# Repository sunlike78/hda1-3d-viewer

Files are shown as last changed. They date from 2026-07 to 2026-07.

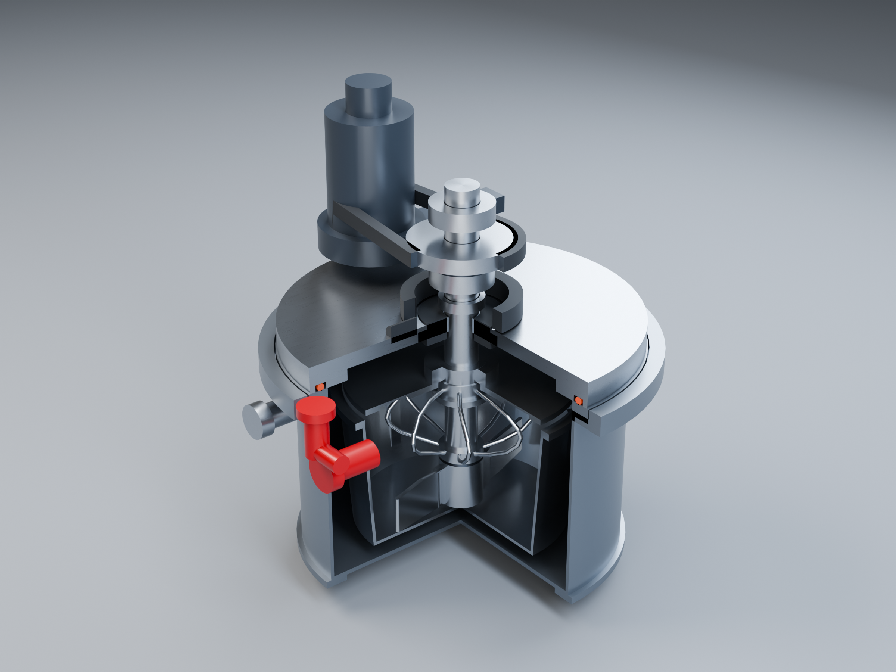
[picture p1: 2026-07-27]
assets/p1/hda1_p1_main_node_photoreal.png

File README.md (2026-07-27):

# HDA-1 interactive 3D viewer

Static GitHub Pages viewer for the HDA-1 domestic foamed-dough appliance main
node. It loads the reviewed STL exports directly, preserves the millimetre
coordinate system, and supports orbit, zoom, pan, cutaway, dimensions, and
per-part visibility.

The visible 11 mm pressure-shell wall and 12 mm bottom are P0 visualization
placeholders, not production dimensions. Pressure boundary, welds, lid, and
lock require a separate code calculation and physical validation.

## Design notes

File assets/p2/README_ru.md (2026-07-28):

# HDA-1 / P2 — предварительный пакет документации

## Главный файл

`hda1_p2_preliminary_documentation_package_ru.pdf` — единый проверенный PDF на 15 страниц:

1. титул, границы проработки и техническая архитектура;
2. ведомость узлов, расчётная сводка и программа верификации;
3. расчёты вала, привода, муфты, подшипников, подачи воздуха, давления, замка и декомпрессии;
4. трассируемость расчётов и ограничения;
5. сборочный лист GA-03 и мобильная обзорная страница с 3D-рендером;
6. GA-05 — подробный сборочный reference-лист, построенный по параметрам нативной модели FreeCAD;
7. приложение с фактическим CAD-рендером из FreeCAD.

## Нативная CAD-модель

- `../freecad/HDA1_P2_Master.FCStd` — исходная параметрическая сборка FreeCAD 1.1.3;
- `../freecad/HDA1_P2_Master.step` — обменная модель STEP;
- `../freecad/HDA1_P2_GA05_Detailed_Reference.pdf` — отдельный лист GA-05;
- `../freecad/HDA1_P2_CAD_Cutaway.png` — CAD-рендер контрольного разреза.

Конструктивное правило, проверяемое во всех материалах: форма имеет сплошное дно, нижней опоры вала в чаше нет; вал поддержан только верхней сухой головкой. Красный элемент на рендере — независимый механический предохранительный клапан.

## Статус

Это предварительная конструкторская проработка P2, а не рабочая документация для изготовления сосуда под давлением. Перед прототипом нужны нормируемый расчёт камеры, крышки и замка, FEM/ресурс, подбор серийных компонентов и физические испытания.

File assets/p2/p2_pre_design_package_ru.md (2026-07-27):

# HDA-1 — пакет P2 для прототипа главного узла

**Версия:** P2 / 28.07.2026  
**Назначение:** предконструкторская база для функционального прототипа бытовой машины на 350–500 г аэрированного теста.  
**Статус:** не является серийной КД, расчётом сосуда по нормам, сертификатом или разрешением на самостоятельное изготовление сосуда под давлением.

## 1. Что изменилось по сравнению с P1

- Убран художественный гибрид лопастей без доказанной функции.
- Появилась P2-форма с постоянным внутренним Ø150 мм, высотой 95 мм и объёмом 1,679 л.
- Новая мешалка имеет реальный параметрический контур: две открытые ленточные спирали и исследовательское щелевое кольцо.
- Подтверждены цифровые зазоры: 7,989 мм по радиусу и 8,0 мм до цельного дна.
- Вал приведён к Ø20 мм; введены расчётные пределы 12 Н·м длительно / 24 Н·м кратковременно.
- Рабочее давление не объявлено заранее: +20 / +40 / +60 кПа — только стендовые точки исследования.

## 2. Параметры P2

| Параметр | Принято |
|---|---:|
| Порция | 350–500 г |
| Форма | Ø150 × 95 мм, 1,679 л номинального геометрического объёма |
| Давление стендовых рецептов | +20 / +40 / +60 кПа |
| Внутренний диаметр камеры | 210 мм |
| Номинальная оболочка P1, сохранённая в P2 | 2,5 мм; нижнее замыкание 3 мм — только до нормального расчёта |
| Крышка / замок | пластина 10 мм; 8 проушин 7 × 18 мм — screening-конверт P1 |
| Мокрый вал | Ø20 мм, кандидат 1.4404/316L |
| Мешалка A | Ø134,02 мм; две открытые ленты |
| Радиальный зазор до формы | 7,989 мм |
| Нижний зазор до цельного дна | 8,0 мм; нижней опоры нет |
| Замес / диспергирование | 50–120 / 180–360 об/мин, исследовательские диапазоны |
| Лимит момента | 12 / 24 Н·м |

## 3. Концептуальный BOM

| Поз. | Узел | Кол. | Кандидат исполнения | Статус |
|---:|---|---:|---|---|
| 1 | Стационарная камера | 1 | 1.4404/316L, сварная, гладкая внутренняя поверхность | Нужен кодовый расчёт |
| 2 | Крышка с верхней головкой | 1 | Нерж. основание + сухой приводной модуль | Нужны FEM и шарнир/рама |
| 3 | Самоблокирующееся кольцо | 1 | 8-проушинная механика | Нужны контакт/усталость |
| 4 | Статическое уплотнение крышки | 1 | Пищевой силикон или FKM по среде | Нужны ресурс и поставщик |
| 5 | Съёмная форма | 1 | Гладкая нержавеющая сталь либо валидированный алюминиевый вариант | Нужна выпечка/мойка |
| 6 | Мешалка A | 1 | Электрополированная нержавеющая сталь, открытая геометрия | Базовый стендовый кандидат |
| 7 | Мокрый вал и муфта | 1 | Ø20 мм, 4 кулачка | Нужны износ/фиксация |
| 8 | Подшипниковый картридж | 1 | 2 подшипника Ø20 вне продуктовой зоны | Нужен конкретный тип |
| 9 | Торцевое уплотнение | 1 | Сменная двойная кассета с дренажной полостью | Нужна квалификация |
| 10 | Привод | 1 | BLDC 600 Вт класса + редуктор + ограничение момента | Нужен подбор |
| 11 | Управляемый выпуск | 1 | НЗ-клапан + ловушка аэрозоля + сменный ограничитель | Нужны расходные испытания |
| 12 | Предохранительный клапан | 1 | Независимый сертифицируемый покупной узел | Настройка только после расчёта |
| 13 | Датчики давления | 2 | Независимые каналы | Нужна диагностика и калибровка |
| 14 | Датчики RPM/тока/температуры/замка | комплект | Независимый контроль процесса | Нужна FMEA |

## 4. Требования к прототипу

1. Вал, инструмент и форма не получают нижней опоры.
2. Крышка не разблокируется по одному датчику или только программой.
3. Рабочий и предохранительный выпуск не объединяются после камеры.
4. Запуск под давлением запрещён при неопознанной форме, неустановленной мешалке, рассогласовании P1/P2 или ненулевых RPM.
5. Нагрузка выше 24 Н·м прекращает замес до прессуризации.
6. Форма, инструмент, экран и уплотнение снимаются без ключа и остаются визуально проверяемыми.

## 5. Ворота перехода P2 → физический прототип

- 54 тестовых цикла по матрице A/B × 20/40/60 кПа × 3 профиля сброса × 3 повтора;
- выбрана одна рецептура для первого окна, без маркетинговых медицинских обещаний;
- результат повторяется минимум в 9 из 10 циклов;
- измерены момент, температура, давление, объём/плотность, оседание и структура после выпечки;
- до давления выше стендового диапазона выполнены профессиональный расчёт, гидроиспытание и валидация клапана.

## 6. Связанные материалы P2

- `main_node_p2.scad` — главная параметрическая сборка;
- `p2_mixer_variants.scad` — варианты A и B;
- `p2_design_basis_ru.md` — входные требования и ограничения;
- `p2_mixer_decision_ru.md` — логика выбора рабочего органа;
- `p2_drive_shaft_screening_ru.md` — привод, вал, муфта, подшипники и воздух;
- `p2_pressure_vent_screening_ru.md` — замок и управляемая декомпрессия;
- `output/drawings/hda1_p2_ga02_ru.svg` — сборочный лист GA-02;
- `output/renders/hda1_p2_main_node_photoreal.png` — проверенный P2-рендер.

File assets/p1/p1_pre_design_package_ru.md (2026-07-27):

# HDA-1 P1 — предконструкторский пакет главного узла

Версия: P1 · дата: 27.07.2026 · статус: **предконструкторская разработка для
прототипа**, не производственная КД и не разрешение на изготовление сосуда.

P1 заменяет только чрезмерно толстую визуальную оболочку P0. Принцип процесса,
съёмная форма, верхнеопорный вал и гибридная мешалка остаются прежними.

## 1. Паспорт P1

| Позиция | Значение P1 | Статус |
|---|---:|---|
| Нормальное давление процесса | до +0,15 МПа | целевое для прототипа |
| Расчётное давление PS | +0,25 МПа | зафиксировано для screening |
| Гидроиспытание | +0,325 МПа | только после расчёта ответственного инженера |
| Расчётная температура TS | до 60 °C | предварительно |
| Камера, внутренний Ø | 210 мм | базовый размер |
| Оболочка камеры | 1.4404 / 316L, номинально 2,5 мм | P1, требует расчёта по нормам |
| Нижнее закрытие камеры | 1.4404 / 316L, номинально 3,0 мм | P1, требует расчёта по нормам |
| Верхний фланец | Ø238 × 10 мм | P1-концепт |
| Крышка | Ø236 × 18 мм; несущая плита 10 мм | P1-концепт |
| Поворотное кольцо | Ø260 × 14 мм; 8 зацепов | P1-концепт |
| Съёмная форма | Ø160 / Ø146 × 92 мм внутри | не является сосудом |
| Полный габарит узла с портами | примерно 282 × 261 × 306 мм | по STL P1 |

## 2. Базы, критические интерфейсы и предварительные допуски

| Обозначение | База / интерфейс | Требование P1 | Почему это критично |
|---|---|---|---|
| A | кольцевая плоскость посадки крышки | плоскостность ≤0,10 мм на дорожке уплотнения | герметичность |
| B | ось вращающегося уплотнения и вала | биение мокрой шейки ≤0,03 мм относительно оси подшипников | ресурс торцевого уплотнения |
| C | три наружных ключа формы | угловое позиционирование ±1°; радиальный люфт ≤0,30 мм | форма не проворачивается |
| D | нижний торец мешалки — внутреннее дно формы | зазор 7,0 ±1,0 мм | нет контакта с чашей, но остаётся перенос теста |
| E | мешалка — стенка формы | радиальный зазор не менее 12 мм | исключение касания при биении |
| F | дорожка статической прокладки | обжатие 15–25 % по паспорту выбранного материала | герметичность без разрушения прокладки |
| G | зацепы кольца | 8 × (7 мм × 18 мм); суммарный рабочий зазор 0,20–0,40 мм | закрытие под давлением |

Размеры B, F и G не должны попадать в производство без итоговой FEA, выбора
уплотнения, цепи допусков и расчёта зацепов. Для мокрой шейки вала в P1
задаётся шлифованная поверхность `Ra ≤ 0,4 мкм`; финальная посадка выбирается
по конкретной кассете уплотнения.

## 3. Состав изделия P1

| Поз. | Наименование | Кол. | Материал / тип | Статус |
|---:|---|---:|---|---|
| 01 | Обечайка камеры с верхним фланцем | 1 | 1.4404, 2,5 мм | собственная, расчёт + WPS/PQR обязательны |
| 02 | Нижнее закрытие камеры с боковым дренажом | 1 | 1.4404, 3,0 мм | собственная, расчёт + WPS/PQR обязательны |
| 03 | Силовая крышка | 1 | 1.4404, плита 10 мм | собственная, FEA обязательна |
| 04 | Поворотное кольцо и восемь зацепов | 1 | 1.4404 | собственная, стендовая проверка обязательна |
| 05 | Статическая прокладка | 1 | пищевой силикон/FKM | покупная, материал и обжатие по поставщику |
| 06 | Съёмная форма | 1 | 1.4301/1.4404, 2,2 мм | продуктовая, не силовая |
| 07 | Вал Ø22 | 1 | 1.4404, шлифованный | собственный/покупной |
| 08 | Два радиально-упорных подшипника | 2 | закрытые, сухая зона | покупные, подбор по нагрузке и ресурсу |
| 09 | Кассета торцевого уплотнения | 1 | пищевое исполнение | покупная/разработка, ресурсный тест |
| 10 | Мешалка P0-hybrid | 1 | 1.4404: лопасти 3 мм, прутки Ø3 мм | прототип, сварка в приспособлении |
| 11 | Датчики давления P1/P2 | 2 | независимые, диапазон с запасом над PS | покупные, проверка канала |
| 12 | Управляемый выпуск | 1 | отдельный клапан | покупной, flow sizing обязателен |
| 13 | Независимый предохранительный клапан | 1 | сертифицированный пружинный | покупной, уставка ≤ PS, расчёт пропускной способности |
| 14 | Датчики замка и формы | 3+ | концевые / бесконтактные | покупные, функциональная безопасность |

Ни резьбы, ни разъёмный крепёж не допускаются в зоне контакта с продуктом.
Сварные швы мешалки зачищаются и электрополируются; шероховатость продуктовых
поверхностей назначается отдельной технологической картой.

## 4. Силовая логика

`давление → крышка → 8 зацепов кольца → верхний фланец → обечайка → нижнее закрытие`.

Мотор, ремень, подшипники, подъёмная кинематика и внешний корпус не являются
частью силовой границы давления. Вал не имеет нижней опоры: его конец и
мешалка находятся на 7 мм над цельным дном съёмной формы. Боковой дренаж
камеры находится за пределами контура формы.

## 5. Обязательная программа квалификации P1

1. **Документальный gate:** утверждение PS/TS, среды, материалов, расчетного
   маршрута, WPS/PQR, NDT и независимого предохранительного клапана.
2. **FEA / расчёт:** оболочка, нижнее закрытие, крышка с отверстием вала,
   фланец, зацепы, контакт прокладки, штуцеры и усиления отверстий.
3. **Герметичность:** пневматическая проверка на безопасном низком давлении с
   защитным экраном и протоколом; гидроиспытание только по утверждённой
   процедуре и после пункта 1–2.
4. **Замок:** минимум 10 000 циклов закрытия/открытия как P1-screening;
   после — контроль износа, усилия поворота и геометрии зацепов.
5. **Сброс:** заблокированный управляемый выпуск, проверка независимого
   клапана, регистрация давления и времени снижения давления.
6. **Привод:** контроль момента, тока, вибрации и биения; отключение при
   заклинивании; проверка 7-мм зазора после ресурса.
7. **Пищевая часть:** разборка без инструмента, мойка, осмотр застойных зон,
   смыв/экстракция после продукта и проверка поверхности.

## 6. Выпуск P2 — что ещё нужно

P2 может быть объявлен только после закрытия FEA/расчётов, испытаний P1,
выбора серийных покупных компонентов, комплекта чертежей с допусками и
спецификациями, FMEA, риск-анализа, инструкций и маршрута соответствия.

Официальная нормативная граница: PED 2014/68/EU относится к оборудованию с
максимальным допустимым давлением выше 0,5 бар; перечень гармонизированных
стандартов поддерживается Европейской комиссией. [PED](https://eur-lex.europa.eu/legal-content/EN/TXT/?qid=1782329382909&uri=CELEX%3A02014L0068), [гармонизированные стандарты](https://single-market-economy.ec.europa.eu/single-market/goods/european-standards/harmonised-standards/pressure-equipment_en).

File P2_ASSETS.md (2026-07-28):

# HDA-1 — пакет P2

Публичные материалы P2:

- `assets/p2/hda1_p2_main_node_photoreal.png` — проверенный фотореалистичный разрез;
- `assets/p2/hda1_p2_ga02_ru.png` — сборочный лист GA-02 на русском;
- `assets/p2/hda1_p2_ga02_ru.svg` — исходный вектор GA-02;
- `assets/p2/hda1_p2_ga02_ru.dxf` — нативный CAD-лист A3 (DXF R2013, слои и размерные примитивы);
- `assets/p2/hda1_p2_mobile_preview_ru.pdf` — двухстраничный просмотр: фоторендер для телефона и лист GA-02 A3;
- `assets/p2/main_node_p2.scad` — параметрическая P2-сборка;
- `assets/p2/main_node_p1.scad` и `assets/p2/p2_mixer_variants.scad` — необходимые подключаемые исходники P2-сборки;
- `assets/p2/p2_pre_design_package_ru.md` — сводный P2-пакет и BOM;
- `assets/p2/p2_drive_shaft_screening_ru.md` — привод, вал, муфта и подшипники;
- `assets/p2/p2_pressure_vent_screening_ru.md` — давление, замок и выпуск;
- `assets/p2/p2_qa_report_ru.md` — цифровая проверка.

Статус: предконструкторская разработка P2. Это не КД для изготовления сосуда под давлением и не сертификация.

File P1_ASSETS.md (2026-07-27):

# HDA-1 — материалы P1

Публичные материалы предконструкторской версии P1:

- `assets/p1/hda1_p1_main_node_photoreal.png` — фотореалистичный рендер;
- `assets/p1/hda1_p1_technical_ru.png` — технический плакат на русском;
- `assets/p1/hda1_p1_ga01_ru.png` — сборочный лист GA-01;
- `assets/p1/main_node_p1.scad` — параметрическая исходная модель OpenSCAD;
- `assets/p1/p1_pre_design_package_ru.md` — BOM, допуски и требования;
- `assets/p1/p1_pressure_lock_screening_ru.md` — предварительная проверка корпуса и замка.

Статус: P1, предконструкторская разработка; не является сертифицированной заводской КД.

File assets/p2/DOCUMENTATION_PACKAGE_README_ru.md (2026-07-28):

# HDA-1 / P2 — предварительный пакет документации

## Главный файл

`hda1_p2_preliminary_documentation_package_ru.pdf` — единый проверенный PDF на 15 страниц:

1. титул, границы проработки и техническая архитектура;
2. ведомость узлов, расчётная сводка и программа верификации;
3. расчёты вала, привода, муфты, подшипников, подачи воздуха, давления, замка и декомпрессии;
4. трассируемость расчётов и ограничения;
5. сборочный лист GA-03 и мобильная обзорная страница с 3D-рендером;
6. GA-06 — подробные проекции и разрезы P2: экранная копия, полученная из нативного DXF экспортом LibreCAD;
7. приложение с фактическим CAD-рендером контрольного разреза из FreeCAD.

## Исходники CAD

- `HDA1_P2_Master.FCStd` — параметрическая сборка FreeCAD 1.1.3;
- `HDA1_P2_Master.step` — обменная BRep-модель STEP;
- `hda1_p2_ga06_detailed_projections_ru.dxf` — нативный исходник подробного листа GA-06;
- `hda1_p2_ga06_librecad_export.pdf` — прямой экспорт DXF из LibreCAD;
- `hda1_p2_ga06_screen_copy_ru.pdf` — проверенная компоновка GA-06, включённая в единый пакет;
- `hda1_p2_freecad_cutaway.png` — CAD-рендер контрольного разреза.

Конструктивное правило, проверяемое во всех материалах: форма имеет сплошное дно, нижней опоры вала в чаше нет; вал поддержан только верхней сухой головкой. Красный элемент на рендере — независимый механический предохранительный клапан.

## Проверки

Выполнены независимые численные проверки расчётов (вал/привод/подшипники, подача воздуха/нагрузка замка) и проверка нативной BRep-модели FreeCAD: 22 объекта, в том числе две твёрдотельные ленты, с ненулевыми объёмами и соблюдением отсутствия нижней опоры в чаше. Визуально проверены лист GA-06 и CAD-разрез, включённые в PDF.

## Статус

Это предварительная конструкторская проработка P2, а не рабочая документация для изготовления сосуда под давлением. Перед прототипом нужны нормируемый расчёт камеры, крышки и замка, FEM/ресурс, подбор серийных компонентов и физические испытания.

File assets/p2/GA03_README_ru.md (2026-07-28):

# GA-03 — актуальный CAD-лист

`hda1_p2_ga03_preliminary_ru.dxf` — лист A3 в DXF R2013.

Проверен открытием в LibreCAD 2.2.1.5: русские подписи читаются штатным
шрифтом `cyrillic_ii.lff`; виды, размерные цепи и текстовые зоны разнесены.
`hda1_p2_ga03_mobile_preview_ru.pdf` построен из той же DXF-геометрии для
быстрого просмотра на телефоне.

Статус: предконструкторская проработка P2, не документация для изготовления.

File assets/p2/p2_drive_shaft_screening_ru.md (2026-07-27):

# HDA-1 — P2: предварительный расчёт привода, вала и воздуха

**Статус:** прозрачный screening P2. Все цифры ниже — входные допущения для компоновки прототипа, а не сертификационные нагрузки.

## 1. Что именно проверено

Проверяется верхний консольный вал без нижней опоры в форме. В расчёте вал нагружен одновременно:

- пиковым крутящим моментом 24 Н·м;
- боковой силой 250 Н на рабочем органе;
- консольным вылетом 120 мм от нижней направляющей/подшипникового узла.

Такое сочетание намеренно жёстче, чем спокойное перемешивание. Оно имитирует густой комок теста и нештатное касание потока продукта, но **не** контакт лопасти с формой: контакт запрещён геометрией и должен быть исключён испытаниями.

## 2. Принятая P2-компоновка

| Элемент | Значение |
|---|---:|
| Мокрый вал | Ø20 мм, 1.4404/316L-кандидат |
| Свободный вылет | 120 мм |
| Нижняя опора в форме | Нет |
| Длительный лимит момента | 12 Н·м |
| Пиковый лимит момента | 24 Н·м, кратковременно |
| Замес | до 120 об/мин |
| Диспергирование | до 360 об/мин |
| Доступная мощность на валу | 450 Вт как допущение для привода 600 Вт класса |
| Свободный объём камеры | 3,6 л для пневматической оценки |

Рекомендуемая механическая схема: два подшипника в сухой головке, ниже них — сменная кассета торцевого уплотнения с дренажным промежутком; затем гладкий мокрый вал. Подшипники не находятся в продуктовой зоне.

## 3. Результаты механического screening

Использованы стандартные упрощённые зависимости для круглого консольного вала:

\[
\sigma_b = \frac{32M}{\pi d^3};\qquad
\tau = \frac{16T}{\pi d^3};\qquad
\sigma_v = \sqrt{\sigma_b^2+3\tau^2}
\]

| Результат | Значение |
|---|---:|
| Изгибающий момент | 30 Н·м |
| Напряжение изгиба | 38,20 МПа |
| Касательное напряжение от кручения | 15,28 МПа |
| Эквивалентное напряжение Мизеса | 46,47 МПа |
| Условный предел текучести 316L | 170 МПа — **не нормативное допускаемое** |
| Предварительный статический запас | 3,66 |
| Прогиб на конце консоли | 0,095 мм |
| Идеальная 1-я частота консоли без массы инструмента | 954 Гц |

Вывод: Ø20 мм — разумная стартовая величина. Это не «доказательство ресурса»: реальная модальная модель обязана включать массу ступицы, ленточного инструмента, муфты и гибкость опор. Даже при грубом понижающем коэффициенте рабочие 6 Гц (360 об/мин) находятся далеко от этой идеальной оценки.

## 4. Совместимость с приводом

| Режим | Момент | Обороты | Механическая мощность |
|---|---:|---:|---:|
| Тяжёлый кратковременный замес | 24 Н·м | 120 об/мин | 302 Вт |
| Диспергирование газа | 3 Н·м | 360 об/мин | 113 Вт |

При 450 Вт доступной механической мощности привод теоретически может выдать 35,8 Н·м на 120 об/мин. Поэтому электронное ограничение 24 Н·м и механическая предохранительная муфта — обязательны: мотор не должен быть источником разрушительной перегрузки.

## 4.1. Быстросъёмная муфта и подшипники

В CAD P2 показана четырёхкулачковая муфта. При радиусе передачи 15 мм пик 24 Н·м создаёт 400 Н на один из четырёх кулачков. Для минимального сечения кулачка 7 × 7 мм среднее касательное напряжение получается **8,16 МПа**. Это лишь первичная проверка среза: финальная муфта требует проверки контактного смятия, люфта, износа от циклов, мойки и фиксации против неполного зацепления.

Для подбора подшипника принят консервативный screening: динамическая грузоподъёмность 7 кН, эквивалентная нагрузка 500 Н и 360 об/мин. Формальный L10 получается около **127 000 часов**. Это не означает такой ресурс изделия: в реальной головке лимит зададут загрязнение, уплотнение, перекос, смазка, старт-стоп и конкретная выбранная серия подшипника. Практическое требование P2 — два подшипника Ø20 мм в сухой зоне, разнесённые по оси; окончательный тип выбирается после компоновки и поставщика.

## 5. Воздух: оценка времени набора давления

Для свободного объёма 3,6 л и насоса с номинальной подачей 6 нормальных л/мин:

| Стендовый уровень | Добавляемый воздух | Идеальное время набора |
|---|---:|---:|
| +20 кПа | 0,71 Нл | 7,1 с |
| +40 кПа | 1,42 Нл | 14,2 с |
| +60 кПа | 2,13 Нл | 21,3 с |

Это нижняя оценка: реальный насос теряет производительность с ростом давления, а клапаны и фильтры создают потери. Для программы следует закладывать минимум двукратный запас времени и оценивать утечки по отдельному тесту герметичности.

## 6. Что этот расчёт ещё не заменяет

- FEM вала, ступицы, ленты и опор с реальной массой;
- усталостную долговечность и ресурс подшипников;
- прочность быстроразъёмной муфты, сварных швов и крышки;
- расчёт торцевого уплотнения по фактической паре трения;
- измерение реального момента на рецептуре;
- расчёт предохранительного клапана и канала сброса.

Исходный код расчёта: [`calculations/p2_drive_shaft_screening.js`](calculations/p2_drive_shaft_screening.js).

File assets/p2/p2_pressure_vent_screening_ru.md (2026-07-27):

# HDA-1 — P2: давление, замок и контролируемый сброс

**Статус:** предварительная воспроизводимая проверка. Не является расчётом сосуда по EN 13445, расчётом предохранительного клапана или подтверждением безопасности.

## 1. Зачем считать два диапазона

В ТЗ нет принятой рабочей уставки давления. Поэтому P2 разделяет:

1. **исследовательский диапазон рецептуры**: +20 / +40 / +60 кПа;
2. **прежний структурный screening-конверт**: +250 кПа и предварительная гидропроба +325 кПа.

Это не разрешение работать на +250 кПа. Такой запас нужен только для того, чтобы не принять крышку/замок, рассчитанные лишь на первый эксперимент.

## 2. Усилие на крышке и восемь проушин

Для внутреннего диаметра камеры 210 мм площадь проёма равна 346,36 см². В расчёт добавлен 1,0 кН предварительного прижима уплотнения. Размер одной проушины принят 7 × 18 мм, количество — 8.

| Перепад давления | Давление на крышку | Полное усилие с уплотнением | На одну проушину | Среднее срезающее напряжение |
|---:|---:|---:|---:|---:|
| +20 кПа | 0,693 кН | 1,693 кН | 0,212 кН | 1,68 МПа |
| +40 кПа | 1,385 кН | 2,385 кН | 0,298 кН | 2,37 МПа |
| +60 кПа | 2,078 кН | 3,078 кН | 0,385 кН | 3,05 МПа |
| +250 кПа, screening-конверт | 8,659 кН | 9,659 кН | 1,207 кН | 9,58 МПа |
| +325 кПа, предварительная гидропроба | 11,257 кН | 12,257 кН | 1,532 кН | 12,16 МПа |

Числа показывают порядок усилий, но не заменяют проверку контакта кольца, изгиба крышки, сварки фланца, локального смятия проушин, эксцентриситета и усталости.

## 3. Контролируемая декомпрессия

Для свободного объёма 3,6 л переход с +60 до +2 кПа высвобождает примерно **2,06 нормального литра воздуха**. Для трёх режимов сброса получаются:

| Время сброса | Средний расход | Эквивалентный диаметр простой диафрагмы* |
|---:|---:|---:|
| 30 с | 4,12 Нл/мин | 0,72 мм |
| 60 с | 2,06 Нл/мин | 0,51 мм |
| 90 с | 1,37 Нл/мин | 0,41 мм |

\*Упрощённая оценка при среднем перепаде 30 кПа, коэффициенте расхода 0,62 и без аэрозоля. Это **не** чертёж дросселя.

Главный конструктивный вывод: отверстие 0,4–0,7 мм в пищевом воздушном тракте слишком чувствительно к загрязнению. Для P2 нужен не «микроотверстие в корпусе», а отдельный сменный дросселирующий картридж либо капиллярный ограничитель, расположенный после ловушки аэрозоля, вместе с нормально-закрытым управляемым выпуском. Независимый предохранительный клапан не должен зависеть от этого тракта.

## 4. Архитектура безопасного выпуска

```text
Камера ──> каплеуловитель/экран ──> управляемый НЗ-клапан ──> сменный ограничитель ──> глушитель ──> наружу
  └──────────────────────────────> независимый механический предохранительный клапан ────────> наружу
```

Пути физически раздельны после камеры. При отключении питания контроллер не открывает крышку; он переходит к безопасному сбросу через выбранную отказобезопасную механику, которую ещё надо определить электрически и испытать.

## 5. Переход к прототипу

На стенде сначала измеряются настоящие кривые давления без теста и с тестом. После этого выбираются:

- рабочее давление рецептуры;
- максимальная скорость набора давления;
- реальное время сброса;
- сечение и материал ограничителя;
- настройка сертифицированного предохранительного клапана.

Исходный код: [`calculations/p2_pressure_vent_screening.js`](calculations/p2_pressure_vent_screening.js).

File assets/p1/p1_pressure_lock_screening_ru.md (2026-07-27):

# HDA-1 P1 — предварительный расчёт силовой оболочки и замка

Дата: 27.07.2026. Расчёт предназначен для выбора разумной **геометрии P1**
перед FEA и расчётом по нормам. Он не является расчётом сосуда по EN 13445 и
не даёт права на изготовление или маркировку CE.

## Зафиксированные исходные условия P1

| Параметр | Принято |
|---|---:|
| Нормальная работа | до +0,15 МПа |
| Расчётное давление PS | +0,25 МПа |
| Предварительное гидроиспытание | +0,325 МПа |
| Расчётная температура | до 60 °C |
| Внутренний диаметр камеры | 210 мм |
| Расчётный объём оболочки | около 4,92 л |
| Материал-кандидат оболочки | 1.4404 / 316L |
| Принятая условная допускаемая величина | 115 МПа |
| Условный коэффициент сварного соединения | 0,85 |

При PS = 2,5 бар и объёме 4,92 л произведение PS·V составляет около
12,3 бар·л. Это не классификация по PED: она зависит от окончательной
конфигурации, группы среды, объёма, защитной арматуры и трактовки всего
изделия. Однако давление выше 0,5 бар уже попадает в область PED.

## Оболочка

Для первичного скрининга использована тонкостенная окружная мембранная модель:

`t = p·D / (2·f·η − p)`.

При +0,25 МПа расчётный мембранный минимум получается около **0,27 мм**, при
+0,325 МПа — около **0,35 мм**. Эти числа нельзя использовать как толщину
детали: в них нет минимальной технологической толщины, допуска проката,
формовки днища, сварных переходов, штуцеров, локальных концентраций,
усталости и коррозионного/полировочного припуска.

Для P1 принята **номинальная стенка 2,5 мм** и нижнее днище 3,0 мм с отдельным
верхним фланцем. Окружное напряжение такой оболочки составляет ориентировочно
6,3 МПа в нормальном режиме, 10,5 МПа при PS и 13,7 МПа при
гидроиспытании. Это только sanity check, а не доказательство прочности.

## Крышка

Крышка P1 — не массивный 28-мм цилиндр P0, а 10-мм верхняя несущая плита,
опирающаяся на кольцевой фланец. Упрощённая формула жёстко защемлённой круглой
пластины Ø210 мм даёт около 11,4 МПа при PS и 14,8 МПа при гидроиспытании.

В финальном расчёте обязательны: центральное отверстие под вращающееся
уплотнение, локальные контактные давления прокладки, жёсткость фланца,
деформация кольца и FEA.

## Поворотный замок

Принято 8 зацепов, каждый с толщиной 7 мм и длиной зацепления 18 мм.

| Проверка при гидроиспытании | Значение |
|---|---:|
| Сила от давления на Ø210 мм | 11,26 кН |
| Предварительное обжатие прокладки | 1,00 кН |
| Полная расчётная сила замка | 12,26 кН |
| На один из 8 зацепов | 1,53 кН |
| Площадь среза одного зацепа | 126 мм² |
| Среднее касательное напряжение | 12,2 МПа |
| Условный запас к 65 МПа | 5,3 |

Это только средний срез. До выпуска P1 в металл нужны контактный расчёт,
изгиб каждого зацепа, допуски поворотного кольца, усталость, защита от
самооткрывания, испытания предельной нагрузки и независимая блокировка при
ненулевом давлении.

## Обязательные ворота перед прототипом

1. Утвердить PS, TS, среду, объём и маршрут соответствия с ответственным
   инженером по оборудованию под давлением.
2. Выполнить EN 13445 / применимый расчёт камеры, днища, крышки, фланца,
   штуцеров, сварки и замка.
3. Выбрать сертифицированный предохранительный клапан с уставкой не выше PS,
   независимый от управляемого выпуска.
4. Провести гидроиспытание, проверку герметичности, ресурсные циклы замка,
   аварийный сброс и FMEA.

Нормативная граница: PED 2014/68/EU применяется к оборудованию с PS выше
0,5 бар. См. официальную [страницу Европейской комиссии](https://single-market-economy.ec.europa.eu/single-market/goods/european-standards/harmonised-standards/pressure-equipment_en) и [текст директивы](https://eur-lex.europa.eu/legal-content/EN/TXT/?qid=1782329382909&uri=CELEX%3A02014L0068).

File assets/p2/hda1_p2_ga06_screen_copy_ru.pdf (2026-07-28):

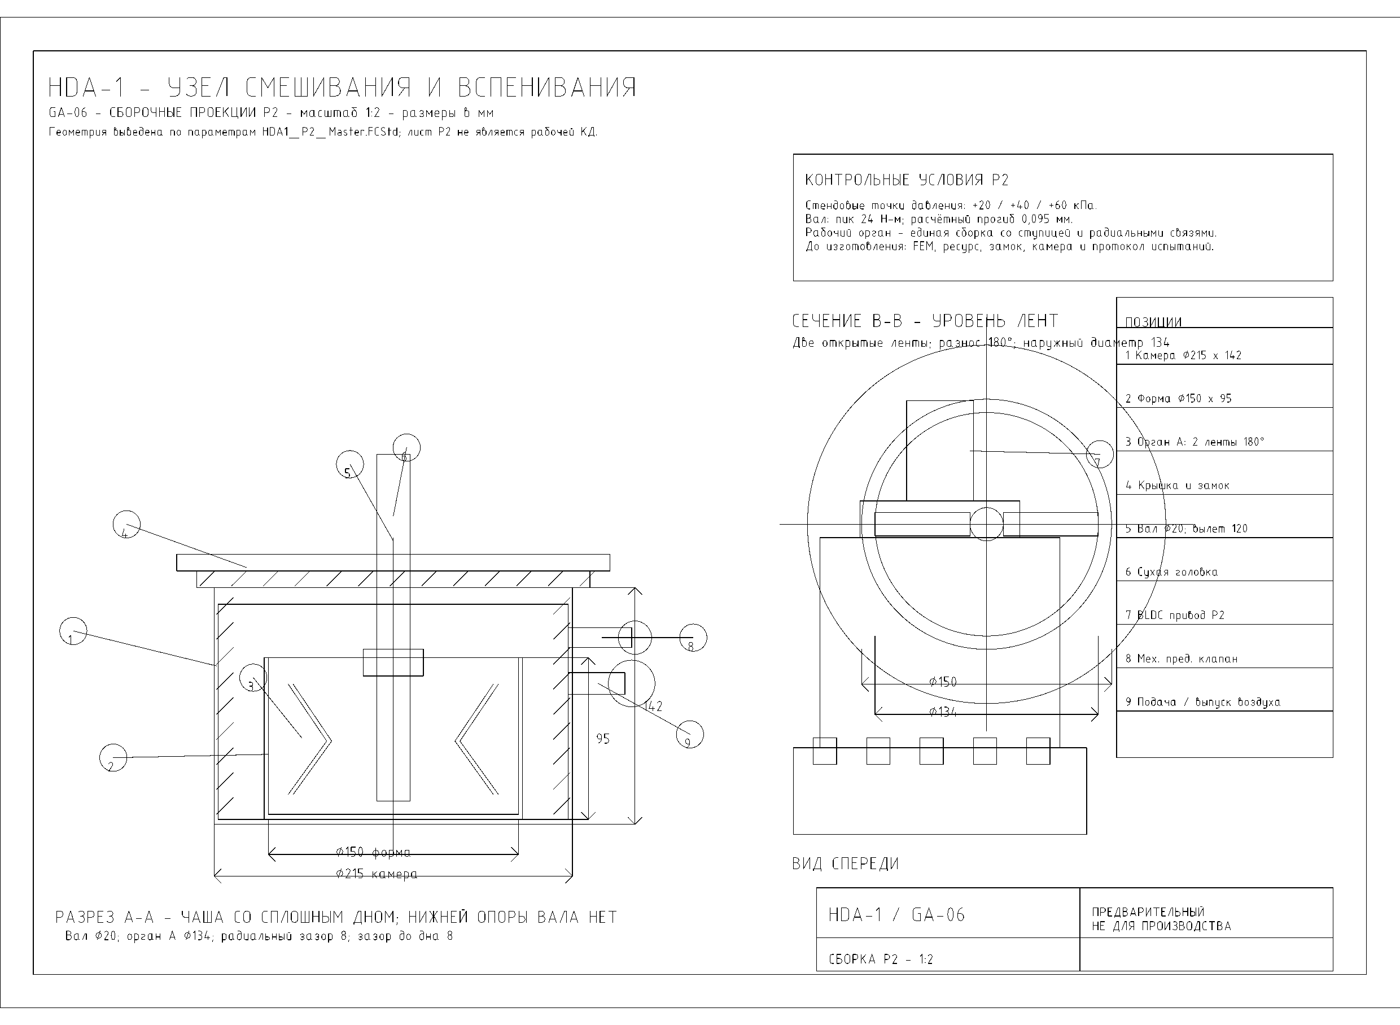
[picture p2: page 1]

GA-06 · экранная копия из нативного DXF, экспортированного LibreCAD | P2 · не для производства

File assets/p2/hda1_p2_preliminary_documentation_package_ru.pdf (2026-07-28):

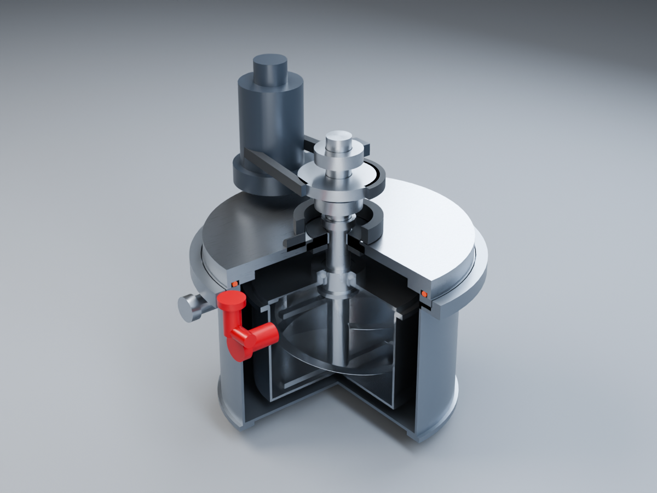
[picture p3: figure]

HDA-1 · P2 · ПРЕДВАРИТЕЛЬНЫЙ КОМПЛЕКТ · НЕ ДЛЯ ИЗГОТОВЛЕНИЯ | Стр. 1

# HDA-1

## Узел смешивания и вспенивания для бытовой машины

### СТАТУС: ПРЕДВАРИТЕЛЬНАЯ КОНСТРУКТОРСКАЯ ПРОРАБОТКА P2

Назначение: проверить компоновку верхнего привода, двухленточного инструмента и цельной съёмной

## формы без нижней опоры вала. Комплект объединяет исходные данные, скрининговые расчёты и

CAD-лист GA-03.

Это не серийная КД, не расчёт сосуда по нормам и не разрешение на самостоятельное изготовление оборудования под давлением.

HDA-1 · P2 · ПРЕДВАРИТЕЛЬНЫЙ КОМПЛЕКТ · НЕ ДЛЯ ИЗГОТОВЛЕНИЯ | Стр. 2

# 0. Статус и состав комплекта

Цель P2 — снять ключевые риски до изготовления прототипа: геометрию рабочего органа, отсутствие нижней опоры, ориентировочную прочность вала, чистоту силового пути и безопасность логики давления. Все численные режимы ниже — исходные для стенда, а не паспорт изделия.

Код | Документ / материал | Назначение
P2-DOC-01 | Настоящий комплект | Единая навигация, сводка решений и открытых пунктов.
GA-03 | Сборочный CAD-лист A3, 1:2 | Разрез A–A, вид сверху, базовые габариты и зазоры.
P2-CALC-01 | Скрининг вала, муфты, подшипников и воздуха | Проверка исходных допущений до FEM и стенда.
P2-SAFE-01 | Скрининг давления, замка и сброса | Разделение стендовых режимов и структурного конверта.
P2-QA-01 | Цифровая QA-проверка | Зазоры, отсутствие нижней опоры, визуальная связность модели.

## Граница ответственности

Перед изготовлением обязательны: финальная 3D-параметрическая модель, FEM и усталость, расчёт

### камеры/крышки/замка по применимой норме, подбор серийных подшипников и уплотнений, анализ

электробезопасности, протоколы мойки и физические испытания продукта.

HDA-1 · P2 · ПРЕДВАРИТЕЛЬНЫЙ КОМПЛЕКТ · НЕ ДЛЯ ИЗГОТОВЛЕНИЯ | Стр. 3

# 1. Техническая архитектура

Подсистема | Принятое решение P2 | Почему
Форма | Съёмная гладкая чаша Ø150; дно цельное. | Нет отверстия и нижнего подшипника в продуктовой зоне; проще очистка.
Мешалка | Две разнесённые на 180° открытые ленточные спирали, съёмная ступица. | Вертикально переносит вязкое тесто и динамически симметрична на 180–360 об/мин.
Вал и опоры | Мокрый вал Ø20; две опоры только в сухой головке сверху. | Сохраняет цельное дно и изолирует подшипники от продукта.
Уплотнение | Сменная двойная торцевая кассета с дренажной полостью. | Разделяет сухую головку и продуктовую зону; нужна квалификация.
Привод | BLDC класса 600 Вт + редуктор + ограничение момента. | Исходный диапазон 50–120 об/мин для замеса и 180–360 об/мин для диспергирования.
Давление | Стендовые точки +20 / +40 / +60 кПа; два датчика, замок, отдельный предохранительный путь. | Режим выбирается данными рецептуры; камера не получает рабочий паспорт из концепта.

Неподвижная нижняя опора, контакт мешалки с формой и открытие крышки при ненулевом давлении — запрещённые состояния конструкции P2.

HDA-1 · P2 · ПРЕДВАРИТЕЛЬНЫЙ КОМПЛЕКТ · НЕ ДЛЯ ИЗГОТОВЛЕНИЯ | Стр. 4

# 2. Ведомость основных узлов (P2)

Поз . | Наименование | Кол. | Материал / исполнение | Статус
1 | Корпус и крышка головки | 1 | Контактные поверхности: AISI 304 или эквивалент; окончательное исполнение TBD. | Компоновка подтверждена
2 | Съёмная форма Ø150 | 1 | Нержавеющая сталь либо валидированный алюминиевый вариант. | Нужны мойка и выпечка
3 | Двухленточный рабочий орган | 1 | Нержавеющая сталь; две симметричные ленты 180°. | Нужна балансировка
4 | Мокрый вал и 4-кулачковая муфта | 1 | Ø20 мм, кандидат 1.4404 / 316L. | Нужны износ и фиксация
5 | Подшипниковый картридж | 1 | Два подшипника Ø20 в сухой зоне. | Нужна конкретная серия
6 | Торцевое уплотнение | 1 | Сменная двойная кассета с дренажной полостью. | Нужна квалификация
7 | Привод | 1 | BLDC 600 Вт класса + редуктор + ограничение момента. | Нужен подбор
8 | Управляемый сброс | 1 | НЗ-клапан, ловушка аэрозоля, сменный ограничитель. | Нужны расходные испытания
9 | Датчики давления | 2 | Независимые каналы; диагностика рассогласования. | Нужны калибровка и логика

Контактные металлы и эластомеры должны быть уточнены по реальным поставщикам, моющим средам и температуре процесса. Данная ведомость — не закупочная спецификация.

HDA-1 · P2 · ПРЕДВАРИТЕЛЬНЫЙ КОМПЛЕКТ · НЕ ДЛЯ ИЗГОТОВЛЕНИЯ | Стр. 5

# 3. Расчётная сводка: что уже проверено

Проверка | Допущение | Результат | Инженерный вывод
Вал Ø20 | 24 Н·м пик; 250 Н боковая сила; консоль 120 мм. | σvM = 46,47 МПа; предварительный статический запас 3,66. | Подходит как стартовая величина; необходимы FEM, моды и усталость.
Муфта | 4 кулачка, радиус передачи 15 мм, сечение 7×7 мм. | Около 400 Н на кулачок; среднее касательное напряжение 8,16 МПа. | Нужны смятие, износ, люфт и защита от неполного зацепления.
Подшипники | C=7 кН; P=500 Н; 360 об/мин. | Формальный L10 ≈ 127 000 ч. | Не паспорт ресурса: лимит зададут перекос, уплотнение, мойка и серия.
Зазоры | CAD-измерение рабочего органа относительно формы. | Радиальный 7,989 мм; до цельного дна 8,0 мм. | Нижней опоры нет; касание формы должно быть исключено стендом.
Давление | Точки исследования +20/+40/+60 кПа. | Это матрица рецептуры; не принятое рабочее давление. | До повышения режима — нормированный расчёт, гидропроба и клапан.

Важно: скрининговый расчёт проверяет порядок величин и помогает не допустить явной компоновочной ошибки. Он не заменяет профессиональный расчёт сосуда под давлением, FEA и ресурсные испытания.

HDA-1 · P2 · ПРЕДВАРИТЕЛЬНЫЙ КОМПЛЕКТ · НЕ ДЛЯ ИЗГОТОВЛЕНИЯ | Стр. 6

# 4. Программа верификации и условия перехода к прототипу

Этап | Что измеряется | Критерий P2 | Далее
Геометрия | Зазоры, биение, балансировка, отсутствие нижней опоры. | ≥7 мм до формы и дна; нет контакта во всём диапазоне оборотов. | Уточнить допуски CAD и технологию изготовления.
Сухой прогон | RPM, ток, вибрация, температура головки, работа муфты. | Без резонансного режима и самопроизвольного расцепления. | Выбрать двигатель, редуктор, подшипники.
Продукт | Момент, температура, плотность/объём, оседание через 1/3/5/10 мин, выпечка. | Момент ниже лимита; достигнут целевой продуктовый критерий. | Выбрать геометрию A/B и режим.
Герметичность | Кривая давления, утечки, контролируемый сброс, P1/P2. | Крышка не открывается до подтверждённого нулевого давления. | Валидировать клапан и межблокировки.
Конструкция | Расчёт камеры/крышки/замка, FEM, сварка, очистка. | Выполнены квалифицированными специалистами по применимым нормам. | Только затем — рабочая КД и испытательный образец.

Переходный критерий: одновременно закрыты геометрический, механический, технологический и безопасностный контуры. Ни один из них не может быть заменён красивым 3D-рендером или только расчётом вала.

## Далее в составе пакета приведён актуальный нативный CAD-лист GA-03 и его

мобильная обзорная страница.

HDA-1 · P2 · ПРЕДВАРИТЕЛЬНЫЙ КОМПЛЕКТ · НЕ ДЛЯ ИЗГОТОВЛЕНИЯ | Стр. 7

# 5. Полный расчётный лист: вал и привод

Модель: верхний круглый консольный вал без нижней опоры в форме. Расчётная комбинация — пиковый крутящий момент T = 24 Н·м, боковая сила F = 250 Н, свободный вылет L = 120 мм, диаметр d = 20 мм. Она моделирует жёсткий ком теста, а не касание инструмента о форму: такое касание конструктивно запрещено.

Шаг | Формула / подстановка | Результат
Изгибающий момент | M = F × L = 250 × 0,120 | 30 Н·м
Изгиб | sigma_b = 32M / (pi × d³) | 38,20 МПа
Кручение | tau = 16T / (pi × d³) | 15,28 МПа
Совместное напряжение | sigma_v = sqrt(sigma_b² + 3 × tau²) | 46,47 МПа
Условный статический запас | n = 170 / 46,47; 170 МПа — ориентир текучести 316L, не нормативный допуск | 3,66
Прогиб консоли | delta = F × L³ / (3 × E × I), E = 193 ГПа | 0,095 мм
Идеальная частота | Консоль без массы инструмента | 954 Гц
Режим | Формула мощности | Результат | Вывод
Тяжёлый кратковременный замес | P = 2 × pi × n × T / 60; n=120; T=24 | 302 Вт | Ниже принятой доступной мощности 450 Вт.
Диспергирование газа | P = 2 × pi × n × T / 60; n=360; T=3 | 113 Вт | Режим требует проверки баланса и нагрева.
Потенциал привода | T = P × 60 / (2 × pi × n); P=450; n=120 | 35,8 Н·м | Нужны электронный лимит 24 Н·м и механическая защита.

Результат применим только как screening: реальная модальная модель должна включить массу ступицы и лент, реальные опоры, муфту, эксцентриситет и циклическую нагрузку. На 360 об/мин рабочая частота 6 Гц; сравнение с 954 Гц не является доказательством отсутствия резонанса в собранном узле.

HDA-1 · P2 · ПРЕДВАРИТЕЛЬНЫЙ КОМПЛЕКТ · НЕ ДЛЯ ИЗГОТОВЛЕНИЯ | Стр. 8

# 6. Полный расчётный лист: муфта, подшипники и набор давления

Проверка | Формула / подстановка | Результат | Ограничение
Четырёхкулачковая муфта | F_кулачка = T / (4 × r) = 24 / (4 × 0,015) | 400 Н | Распределение нагрузки в реальной муфте может быть неравномерным.
Срез кулачка 7×7 мм | tau = F / A = 400 / (7×7) | 8,16 МПа | Не проверены смятие, люфт, циклический износ и неполное зацепление.
Подшипники, L10 | L10h = (C/P)^3 × 10^6 / (60 × n); C=7000 Н; P=500 Н; n=360 | ≈127 000 ч | Формальный ресурс; не ресурс головки в мойке и с перекосом.

Подача воздуха: свободный объём V = 3,6 л; V_N = V × delta_p / p_atm; p_atm = 101,3 кПа; t = V_N / Q.

Стендовая точка | Добавляемый нормальный объём | Формула | Идеальное время при 6 Нл/мин
+20 кПа | 0,71 Нл | V_N = 3,6 × 20 / 101,3 | 7,1 с
+40 кПа | 1,42 Нл | V_N = 3,6 × 40 / 101,3 | 14,2 с
+60 кПа | 2,13 Нл | V_N = 3,6 × 60 / 101,3 | 21,3 с

Время — нижняя оценка. Реальный насос теряет подачу с ростом давления, а фильтры и клапаны дают потери; для эксперимента закладывается минимум двукратный запас времени и отдельный тест утечек.

HDA-1 · P2 · ПРЕДВАРИТЕЛЬНЫЙ КОМПЛЕКТ · НЕ ДЛЯ ИЗГОТОВЛЕНИЯ | Стр. 9

# 7. Полный расчётный лист: усилие на крышке и замок

Базовая геометрия: внутренний диаметр камеры D = 210 мм. Площадь проёма A = pi × D² / 4 = 0,034636 м² = 346,36 см². К усилию давления добавлен предварительный прижим уплотнения 1,0 кН. Принято восемь проушин 7×18 мм.

Перепад | Сила давления Fp = p × A | Итого F = Fp + 1,0 кН | На проушину F/8 | Среднее tau = F/(8×7×18)
+20 кПа | 0,693 кН | 1,693 кН | 0,212 кН | 1,68 МПа
+40 кПа | 1,385 кН | 2,385 кН | 0,298 кН | 2,37 МПа
+60 кПа | 2,078 кН | 3,078 кН | 0,385 кН | 3,05 МПа
+250 кПа, screening-конверт | 8,659 кН | 9,659 кН | 1,207 кН | 9,58 МПа
+325 кПа, предварительная гидропроба | 11,257 кН | 12,257 кН | 1,532 кН | 12,16 МПа

+250 кПа и +325 кПа — только структурный screening-конверт, а не разрешённое рабочее давление. Таблица даёт порядок усилий. Она не проверяет изгиб крышки, контакт кольца, сварки, локальное смятие проушин, эксцентриситет, усталость и сертифицированный предохранительный клапан.

Правило безопасности P2: крышка остаётся заблокированной при ненулевом давлении;

## два датчика P1/P2, независимый механический предохранительный путь и

управляемый выпуск имеют раздельные функции.

HDA-1 · P2 · ПРЕДВАРИТЕЛЬНЫЙ КОМПЛЕКТ · НЕ ДЛЯ ИЗГОТОВЛЕНИЯ | Стр. 10

# 8. Полный расчётный лист: контролируемая декомпрессия

Для свободного объёма 3,6 л переход от +60 кПа до +2 кПа высвобождает V_N = 3,6 × (60−2) / 101,3 = 2,06 Нл воздуха. Средний расход Q = V_N / t. Эквивалентное отверстие ниже вычислено упрощённо: Q = Cd × A × sqrt(2 × delta_p / rho), где Cd=0,62, средний перепад 30 кПа и аэрозоль не учитывается.

Время сброса | Средний расход | Эквивалентный диаметр простой диафрагмы | Конструкторское решение
30 с | 4,12 Нл/мин | 0,72 мм | Не делать микроотверстие в корпусе.
60 с | 2,06 Нл/мин | 0,51 мм | Сменный дроссель или капилляр после ловушки аэрозоля.
90 с | 1,37 Нл/мин | 0,41 мм | Отдельно подтвердить загрязняемость и повторяемость.

Расчёт объясняет, почему контролируемый выпуск не должен зависеть от случайной маленькой дырки: сечение 0,4–0,7 мм в пищевом воздушном тракте чувствительно к загрязнению. Предлагается отдельный сменный ограничитель после ловушки аэрозоля и нормально-закрытого управляемого клапана; независимый предохранительный клапан идёт отдельной ветвью.

Что не рассчитано этим пакетом: реальная характеристика насоса и клапанов, двухфазный поток с аэрозолем, конкретная настройка сертифицированного клапана, герметичность уплотнения и тепловой режим. Это измеряется на стенде и закрывается поставщиками компонентов.

HDA-1 · P2 · ПРЕДВАРИТЕЛЬНЫЙ КОМПЛЕКТ · НЕ ДЛЯ ИЗГОТОВЛЕНИЯ | Стр. 11

# 9. Трассируемость расчётов и честный статус

Раздел | Исходный материал / код | Что подтверждает
Геометрия и зазоры | P2 QA; параметрическая 3D-модель | 7,989 мм по радиусу; 8,0 мм до цельного дна; нижней опоры нет.
Мешалка | P2 решение по вариантам A/B | Базовый кандидат — две открытые ленты на 180°; вариант B экспериментальный.
Вал, привод, муфта, подшипники, воздух | calculations/p2_drive_shaft_screening.js | Воспроизводимые screening-значения, развёрнутые на стр. 7–8 PDF.
Давление, замок, выпуск | calculations/p2_pressure_vent_screening.js | Воспроизводимые screening-значения, развёрнутые на стр. 9–10 PDF.
CAD | GA-03, DXF R2013 | Разрез, вид сверху, базовые размеры и зазоры; не рабочая КД.

Итог: теперь PDF содержит все выполненные в P2 численные screening-расчёты, их формулы, подстановки, допущения и границы применимости. Это не означает, что узел «научно доказан» для производства. Для такого статуса остаются обязательными FEM, нормированный расчёт камеры и замка, ресурс, подбор покупных компонентов и физическая программа испытаний 2 геометрии × 3 давления × 3 профиля сброса × минимум 3 повтора = 54 цикла.

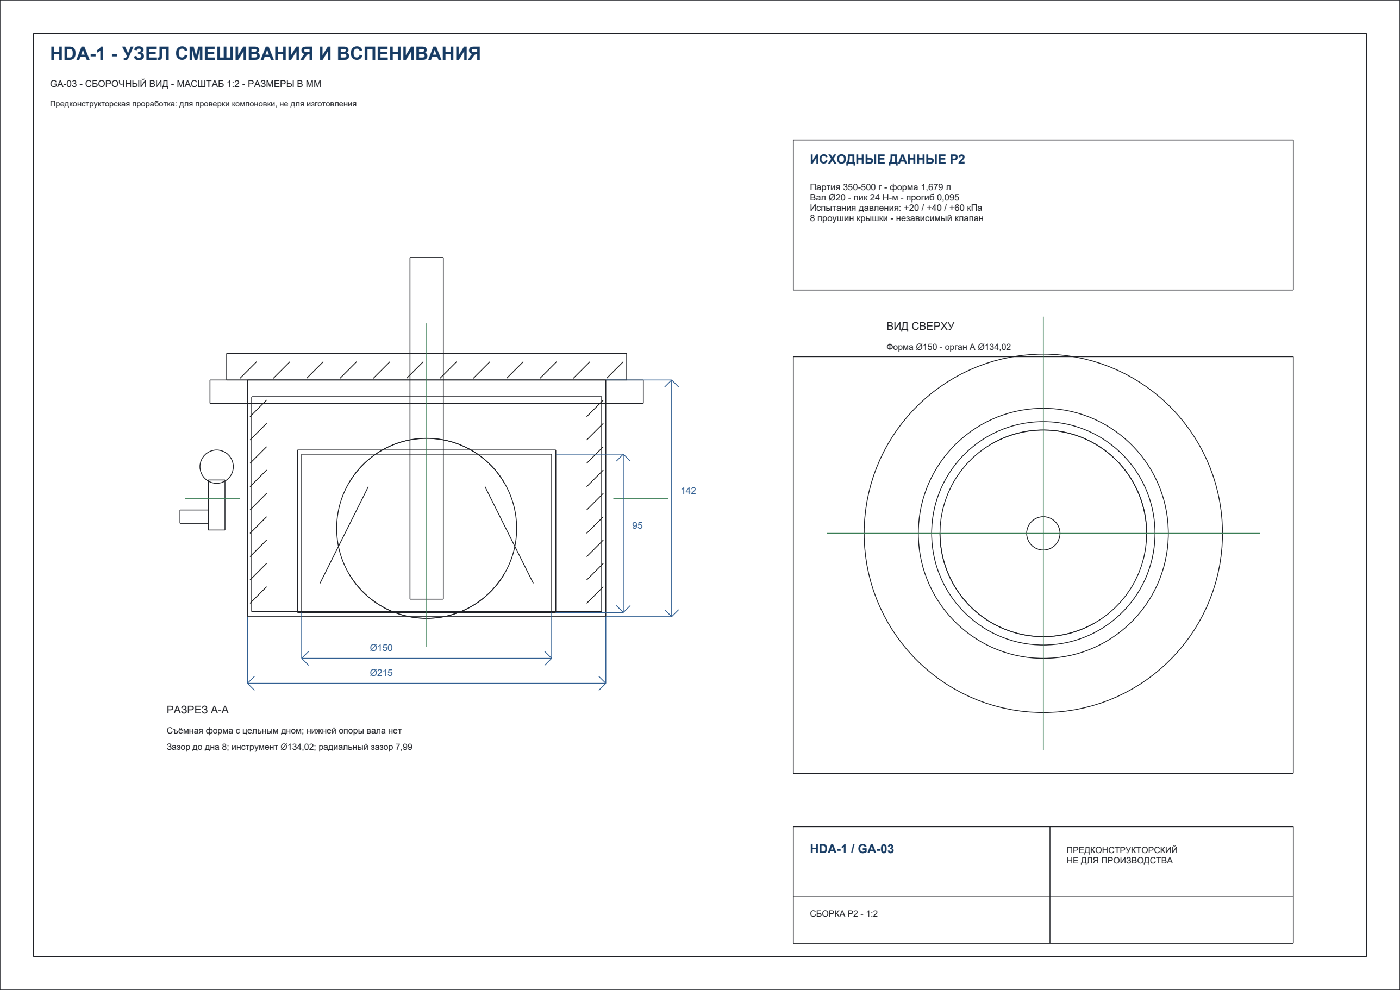
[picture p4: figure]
HDA-1 - УЗЕЛ СМЕШИВАНИЯ И ВСПЕНИВАНИЯ; РАЗРЕЗ А-А; ВИД СВЕРХУ; Форма Ø150 - орган A Ø134,02; ИСХОДНЫЕ ДАННЫЕ P2; Партия 350-500 г - форма 1,679 л Вал Ø20 - пик 24 Н-м - прогиб 0,095 Испытания давления: +20 / +40 / +60 кПа 8 проушин крышки - независимый клапан; СБОРКА P2 - 1:2

GA-03 - СБОРОЧНЫЙ ВИД - МАСШТАБ 1:2 - РАЗМЕРЫ В ММ

Предконструкторская проработка: для проверки компоновки, не для изготовления

Съёмная форма с цельным дном; нижней опоры вала нет

Зазор до дна 8; инструмент Ø134,02; радиальный зазор 7,99

HDA-1 / GA-03 | ПРЕДКОНСТРУКТОРСКИЙ НЕ ДЛЯ ПРОИЗВОДСТВА

# HDA-1 · главный узел P2

Предконструкторский просмотр. Не документ для производства.

## Что показано

- Бытовая партия: 350–500 г; съёмная форма Ø150 × 95 мм, 1,679 л.
- Рабочий орган A: две открытые ленточные спирали Ø134,02 мм.
- Вал Ø20 мм, передача через верхнюю муфту; нижней опоры в чаше нет.
- Зазор до цельного дна формы — 8 мм; радиальный зазор — 7,99 мм.
- Расчётный пик — 24 Н·м; испытательные давления: +20/+40/+60 кПа.

Технический лист — следующая страница (A3, альбомная).

Редактируемый первоисточник: hda1_p2_ga03_preliminary_ru_v4.dxf (DXF R2013).


GA-06 · экранная копия из нативного DXF, экспортированного LibreCAD | P2 · не для производства

# HDA-1 / P2 — CAD-РЕНДЕР ИЗ НАТИВНОЙ МОДЕЛИ FreeCAD

Проверочный разрез сборки: отдельные тела, чаша с цельным дном, верхний вал и внешние пневмоузлы.

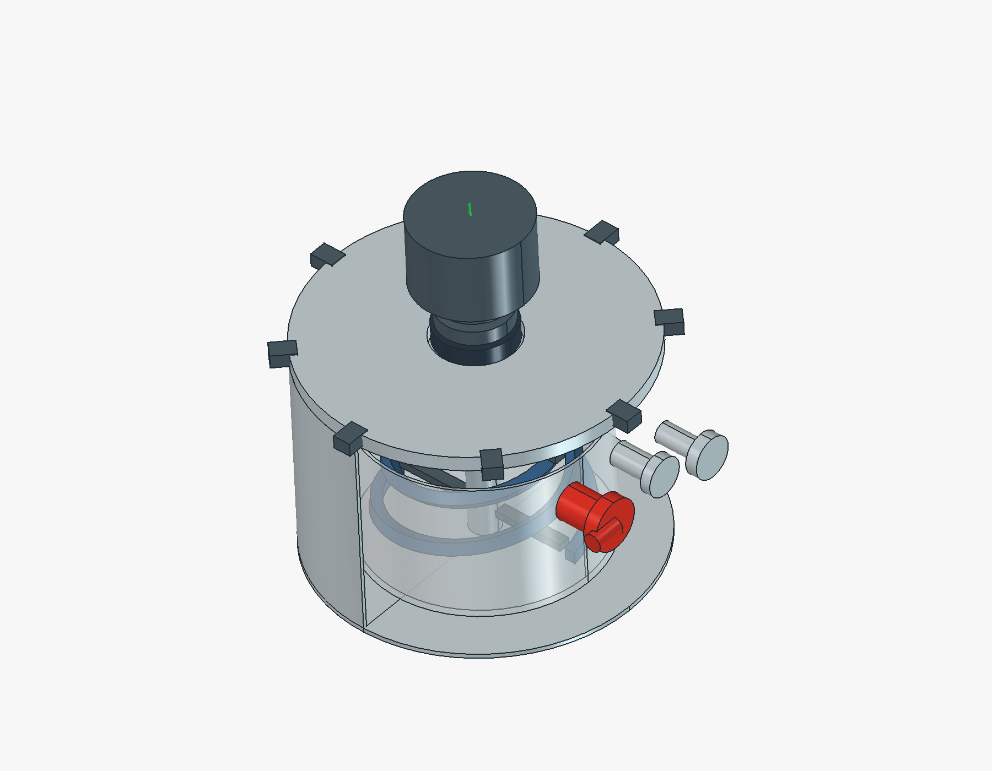
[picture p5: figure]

Что подтверждает этот кадр

- сборка открыта и сохранена в FreeCAD 1.1.3 как HDA1_P2_Master.FCStd;
- корпус показан половиной для визуальной проверки внутренней компоновки;
- нижний подшипник в форме отсутствует; красный элемент — независимый механический клапан;
- STEP-обменник и исходная FreeCAD-модель приложены отдельно.

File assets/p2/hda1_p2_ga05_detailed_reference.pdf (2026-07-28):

# HDA-1 — УЗЕЛ СМЕШИВАНИЯ И ВСПЕНИВАНИЯ

## GA-05 · ДЕТАЛЬНЫЙ СБОРОЧНЫЙ ЛИСТ ПО ПАРАМЕТРИЧЕСКОЙ МОДЕЛИ FreeCAD · P2

Размеры — опорные для прототипа; лист не является рабочей КД и не разрешает изготовление сосуда под давлением.

### Ø215 камера

### Ø150 форма

### Ø134 орган A

142

95

### зазор 8

### РАЗРЕЗ A–A · ЧАША С ЦЕЛЬНЫМ ДНОМ · НИЖНЕЙ ОПОРЫ ВАЛА НЕТ

1

2 3

4

5

### ВИД СВЕРХУ · ДЛЯ ПРОВЕРКИ ЗАЗОРОВ

Ø150

Ø134

Радиальный зазор: 7,989 мм

### ПОЗИЦИИ И КРИТИЧЕСКИЕ ПАРАМЕТРЫ

1 | Камера | Ø215 внешн. / Ø210 внутр. / H142; стенка 2,5 screening
2 | Съёмная форма | Ø150 × H95; дно цельное, нижней опоры нет
3 | Рабочий орган A | две открытые ленты 180°; Ø134; H76
4 | Крышка и замок | плита 10; 8 позиций замыкания
5 | Вал | Ø20; кандидат 1.4404/316L; вылет 120
6 | Сухая головка | 2 подшипника Ø20 + кассета уплотнения
7 | Привод | BLDC 600 Вт класса; лимит 12/24 Н·м
8 | Красный узел | независимый механический предохранительный клапан
9 | Пневмолинии | подача и управляемый выпуск — раздельные пути

### ПРОВЕРОЧНЫЕ УСЛОВИЯ P2

- давление рецептуры: +20 / +40 / +60 кПа — только стендовые точки;
- крышка открывается только после подтверждённого нулевого давления;
- зазоры измерены цифрово; окончательные допуски — после FEM и прототипа.

## HDA-1 / GA-05

СБОРКА P2 · 1:1 reference

ПРЕДВАРИТЕЛЬНЫЙ

НЕ ДЛЯ ПРОИЗВОДСТВА

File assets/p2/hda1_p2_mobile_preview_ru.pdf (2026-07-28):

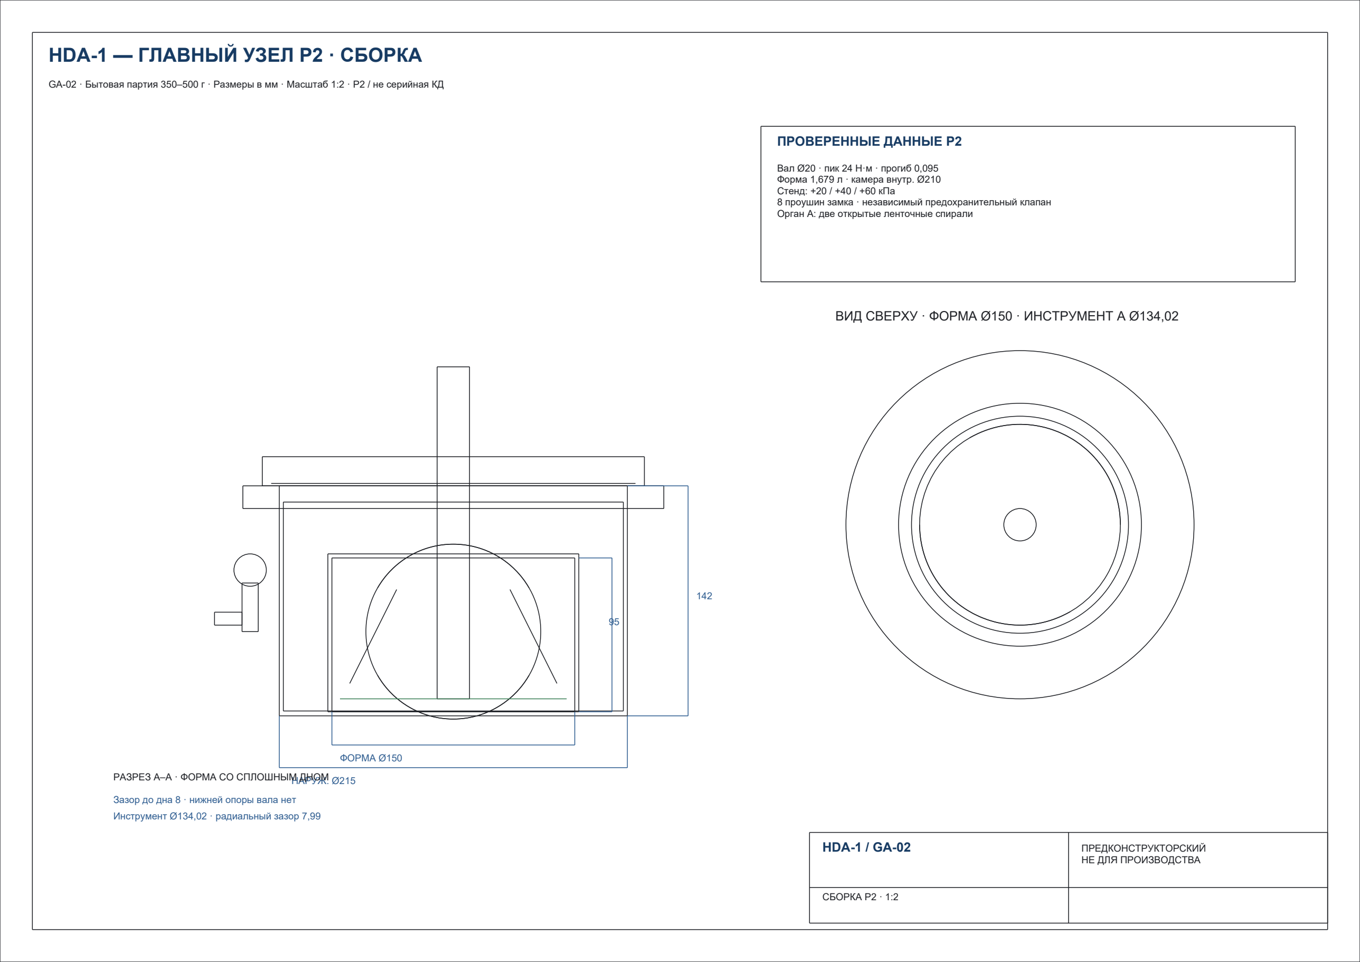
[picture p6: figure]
HDA-1 — ГЛАВНЫЙ УЗЕЛ P2 · СБОРКА; НАРУЖ. Ø215; ФОРМА Ø150; РАЗРЕЗ А–А · ФОРМА СО СПЛОШНЫМ ДНОМ; Зазор до дна 8 · нижней опоры вала нет; ПРОВЕРЕННЫЕ ДАННЫЕ P2; Вал Ø20 · пик 24 Н·м · прогиб 0,095 Форма 1,679 л · камера внутр. Ø210 Стенд: +20 / +40 / +60 кПа; Орган A: две открытые ленточные спирали; СБОРКА P2 · 1:2

GA-02 · Бытовая партия 350–500 г · Размеры в мм · Масштаб 1:2 · P2 / не серийная КД

Инструмент Ø134,02 · радиальный зазор 7,99

## ВИД СВЕРХУ · ФОРМА Ø150 · ИНСТРУМЕНТ A Ø134,02

8 проушин замка · независимый предохранительный клапан

HDA-1 / GA-02 | ПРЕДКОНСТРУКТОРСКИЙ НЕ ДЛЯ ПРОИЗВОДСТВА

# HDA-1 · главный узел P2

Предконструкторский просмотр. Не документ для производства.


## Что показано

- Бытовая партия: 350–500 г; съёмная форма Ø150 × 95 мм, 1,679 л.
- Рабочий орган A: две открытые ленточные спирали Ø134,02 мм.
- Вал Ø20 мм, передача через верхнюю муфту; нижней опоры в чаше нет.
- Зазор до цельного дна формы — 8 мм; радиальный зазор — 7,99 мм.
- Расчётный пик — 24 Н·м; испытательные давления: +20/+40/+60 кПа.

Технический лист — следующая страница (A3, альбомная).

Редактируемый первоисточник: hda1_p2_ga02_ru.dxf (DXF R2013).

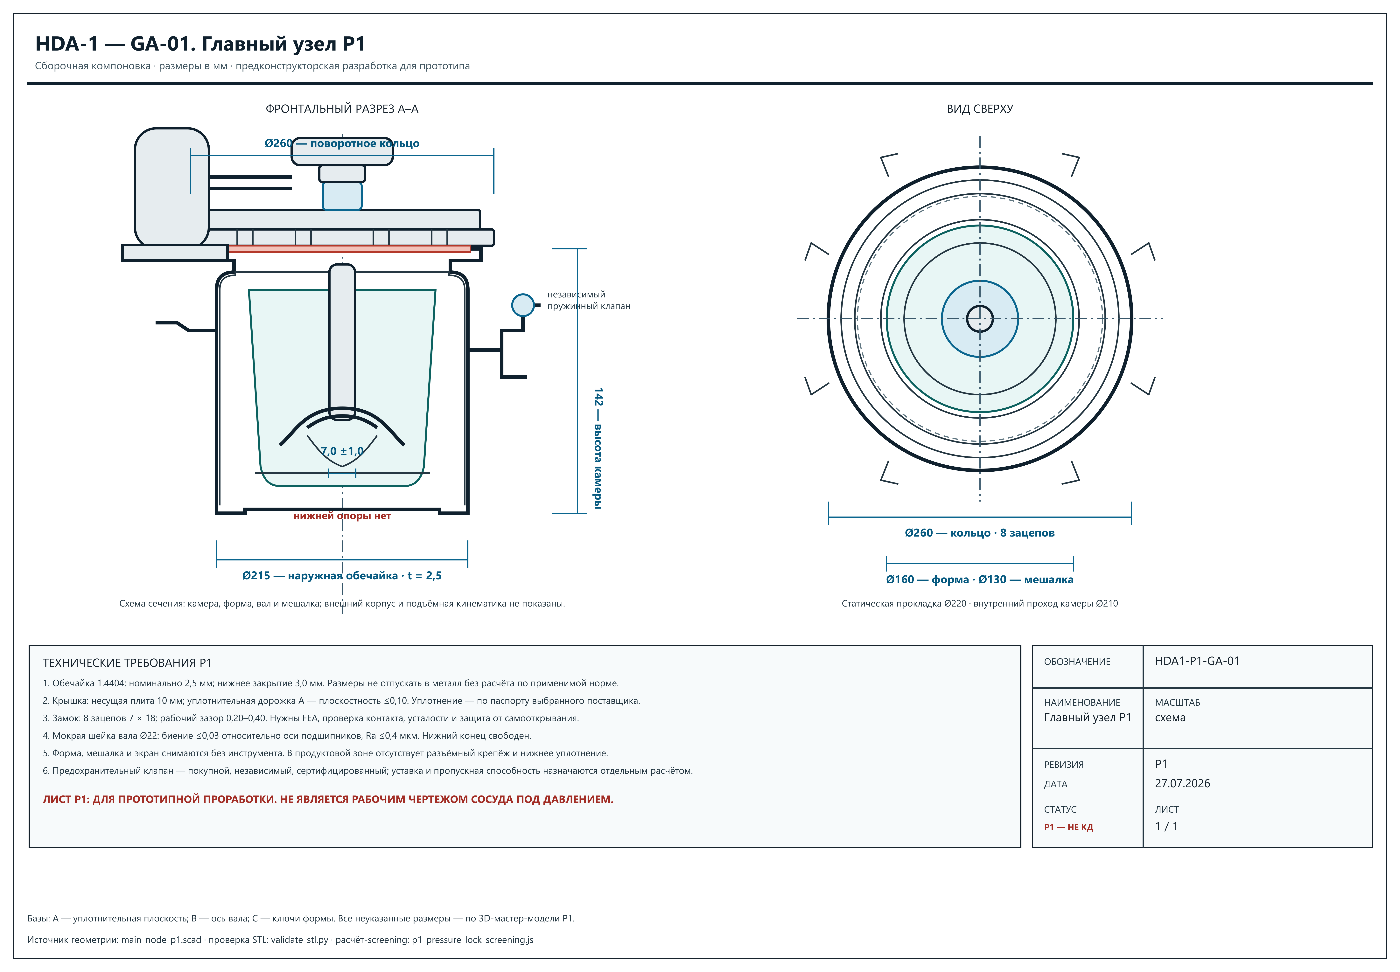
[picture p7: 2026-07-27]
assets/p1/hda1_p1_ga01_ru.png

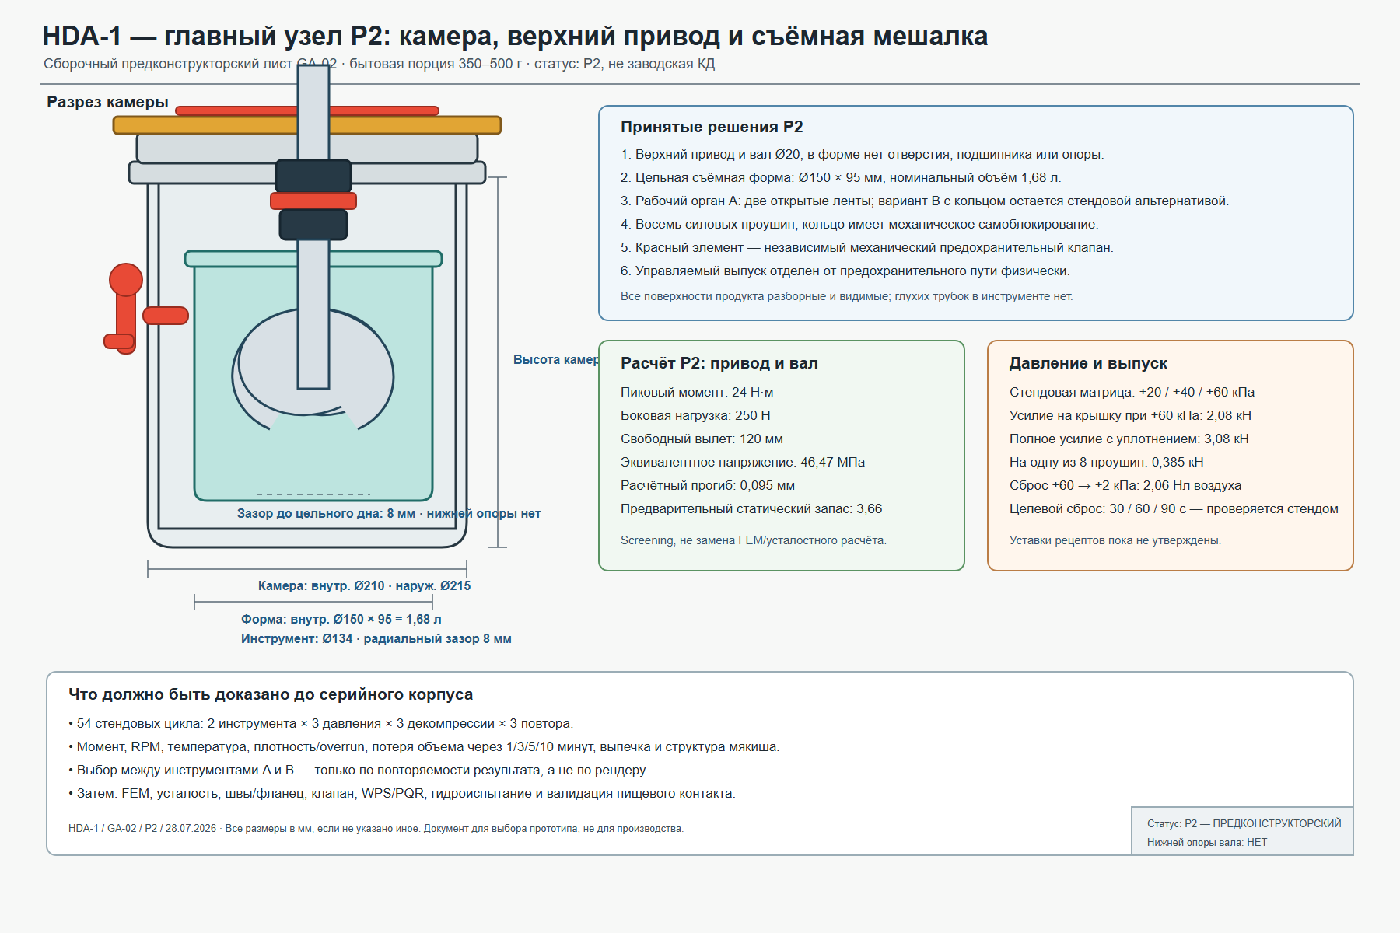
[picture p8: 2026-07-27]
assets/p2/hda1_p2_ga02_ru.png

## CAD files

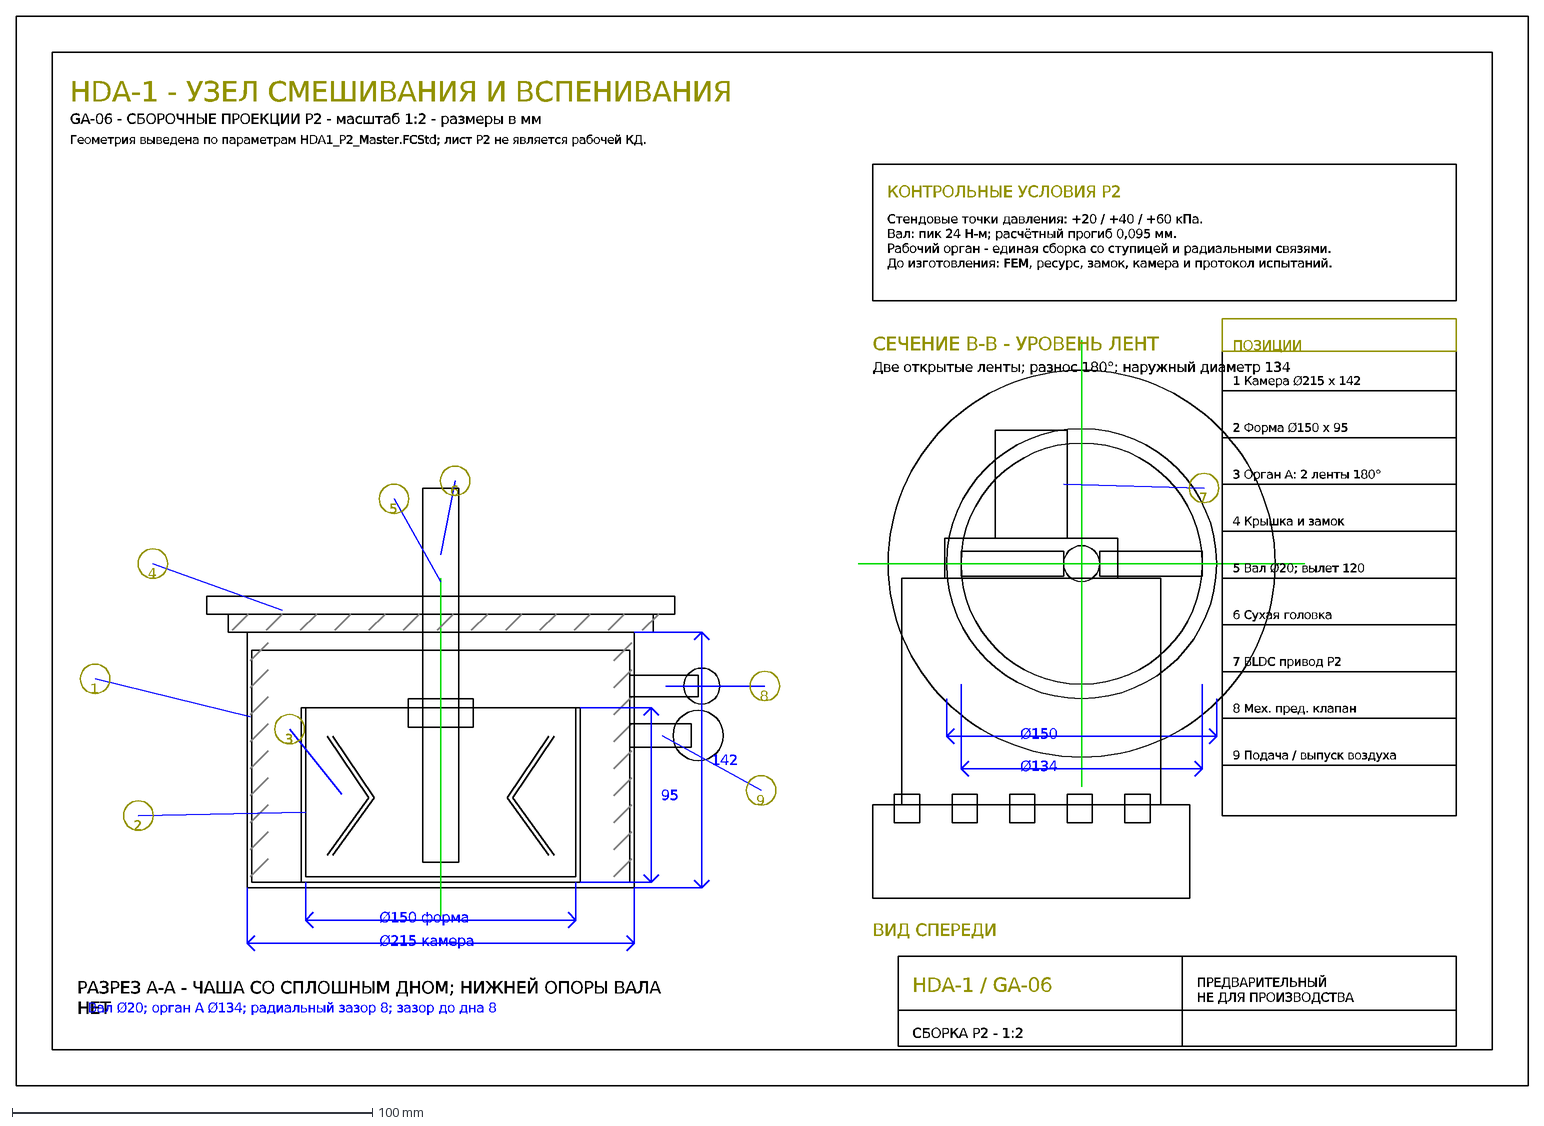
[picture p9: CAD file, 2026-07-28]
assets/p2/hda1_p2_ga06_detailed_projections_ru.dxf
HDA-1 - УЗЕЛ СМЕШИВАНИЯ И ВСПЕНИВАНИЯ
GA-06 - СБОРОЧНЫЕ ПРОЕКЦИИ P2 - масштаб 1:2 - размеры в мм
Геометрия выведена по параметрам HDA1_P2_Master.FCStd; лист P2 не является рабочей КД.
Ø215 камера
Ø150 форма
142
95
РАЗРЕЗ A-A - ЧАША СО СПЛОШНЫМ ДНОМ; НИЖНЕЙ ОПОРЫ ВАЛА НЕТ
Вал Ø20; орган A Ø134; радиальный зазор 8; зазор до дна 8
1
2
3
4
5
6
8
9
СЕЧЕНИЕ B-B - УРОВЕНЬ ЛЕНТ
Две открытые ленты; разнос 180°; наружный диаметр 134
Ø150
Ø134
ВИД СПЕРЕДИ
7
ПОЗИЦИИ
1 Камера Ø215 x 142
2 Форма Ø150 x 95
3 Орган A: 2 ленты 180°
4 Крышка и замок
5 Вал Ø20; вылет 120
6 Сухая головка
7 BLDC привод P2
8 Мех. пред. клапан
9 Подача / выпуск воздуха
КОНТРОЛЬНЫЕ УСЛОВИЯ P2
Стендовые точки давления: +20 / +40 / +60 кПа. Вал: пик 24 Н-м; расчётный прогиб 0,095 мм. Рабочий орган - единая сборка со ступицей и радиальными связями. До и
HDA-1 / GA-06
СБОРКА P2 - 1:2
ПРЕДВАРИТЕЛЬНЫЙ НЕ ДЛЯ ПРОИЗВОДСТВА

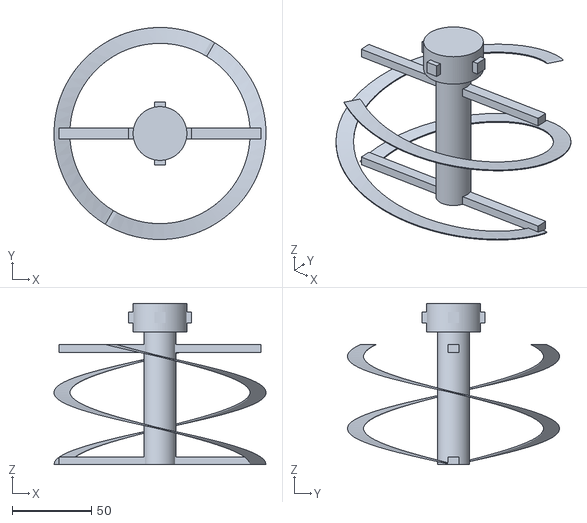
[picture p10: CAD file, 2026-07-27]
models/hda1_mixer.stl
134.0 x 134.0 x 102.0

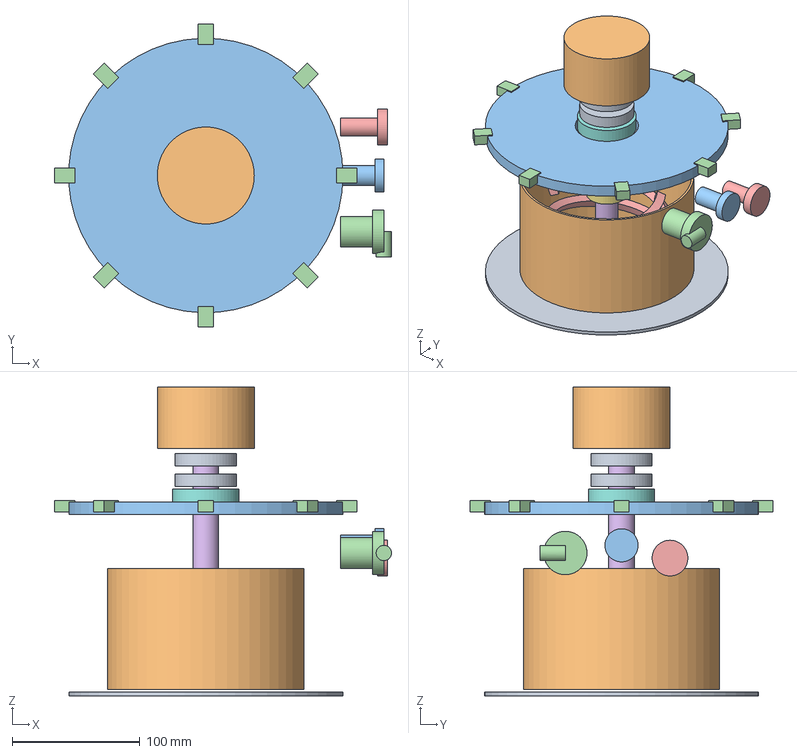
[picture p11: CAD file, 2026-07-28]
assets/p2/HDA1_P2_Master.step
264.0 x 237.0 x 242.0 mm
02 — Нижнее закрытие камеры
03 — Съёмная форма Ø150 × 95, цельное дно
04 — Крышка с верхней приводной головкой
05 — 8-позиционный кольцевой замок крышки
06 — Двухленточный рабочий орган A, 180°
07 — Мокрый вал Ø20, верхняя консоль
08 — Ступица рабочего органа
09 — Двойная торцевая кассета с дренажной полостью
10 — Два подшипника Ø20 в сухой головке
11 — Привод BLDC 600 Вт класса + редуктор
12 — Патрубок подачи воздуха
13 — Независимый механический предохранительный клапан
14 — Управляемый выпуск / сменный ограничитель

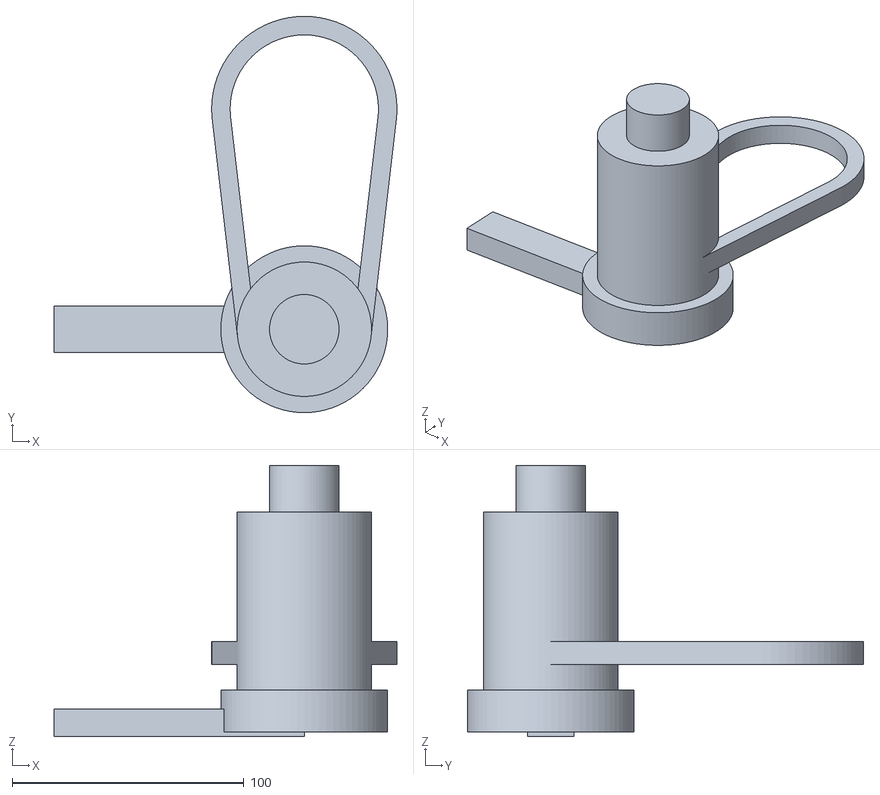
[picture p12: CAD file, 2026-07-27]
models/hda1_motor.stl
148.0 x 171.0 x 117.0

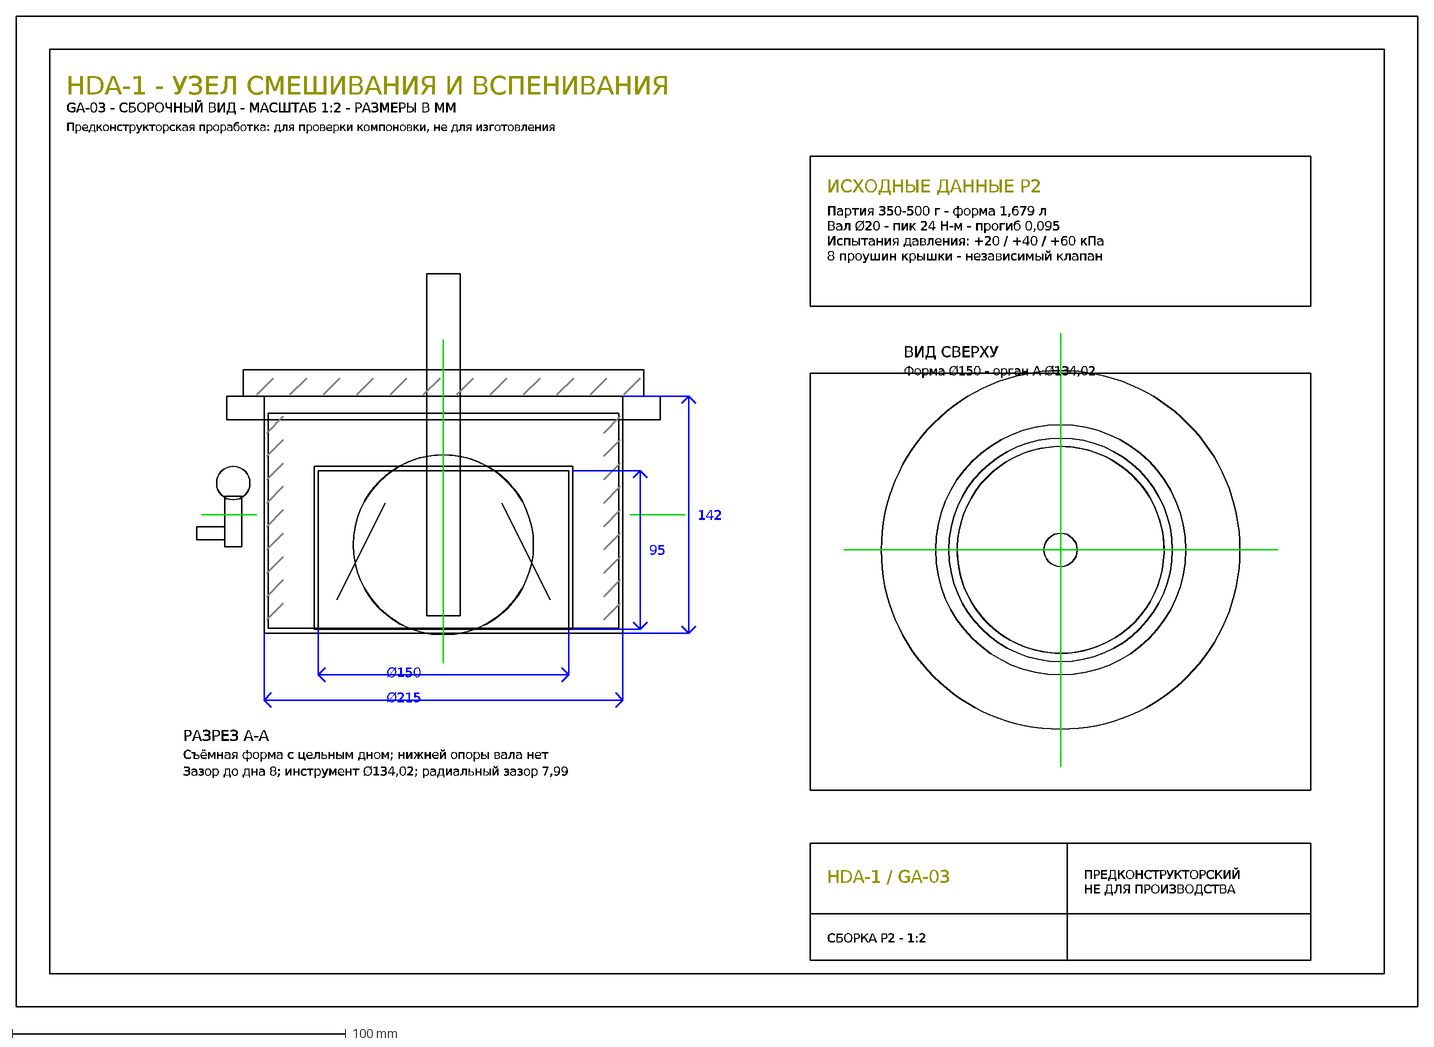
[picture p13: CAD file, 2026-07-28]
assets/p2/hda1_p2_ga03_preliminary_ru.dxf
HDA-1 - УЗЕЛ СМЕШИВАНИЯ И ВСПЕНИВАНИЯ
GA-03 - СБОРОЧНЫЙ ВИД - МАСШТАБ 1:2 - РАЗМЕРЫ В ММ
Предконструкторская проработка: для проверки компоновки, не для изготовления
Ø215
Ø150
142
95
РАЗРЕЗ А-А
Съёмная форма с цельным дном; нижней опоры вала нет
Зазор до дна 8; инструмент Ø134,02; радиальный зазор 7,99
ВИД СВЕРХУ
Форма Ø150 - орган A Ø134,02
ИСХОДНЫЕ ДАННЫЕ P2
Партия 350-500 г - форма 1,679 л Вал Ø20 - пик 24 Н-м - прогиб 0,095 Испытания давления: +20 / +40 / +60 кПа 8 проушин крышки - независимый клапан
HDA-1 / GA-03
СБОРКА P2 - 1:2
ПРЕДКОНСТРУКТОРСКИЙ НЕ ДЛЯ ПРОИЗВОДСТВА

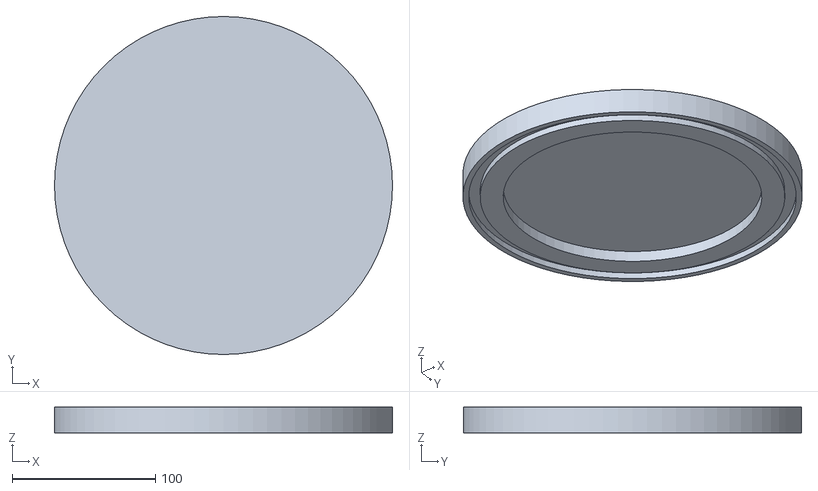
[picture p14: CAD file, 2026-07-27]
models/hda1_lid.stl
236.0 x 236.0 x 18.0

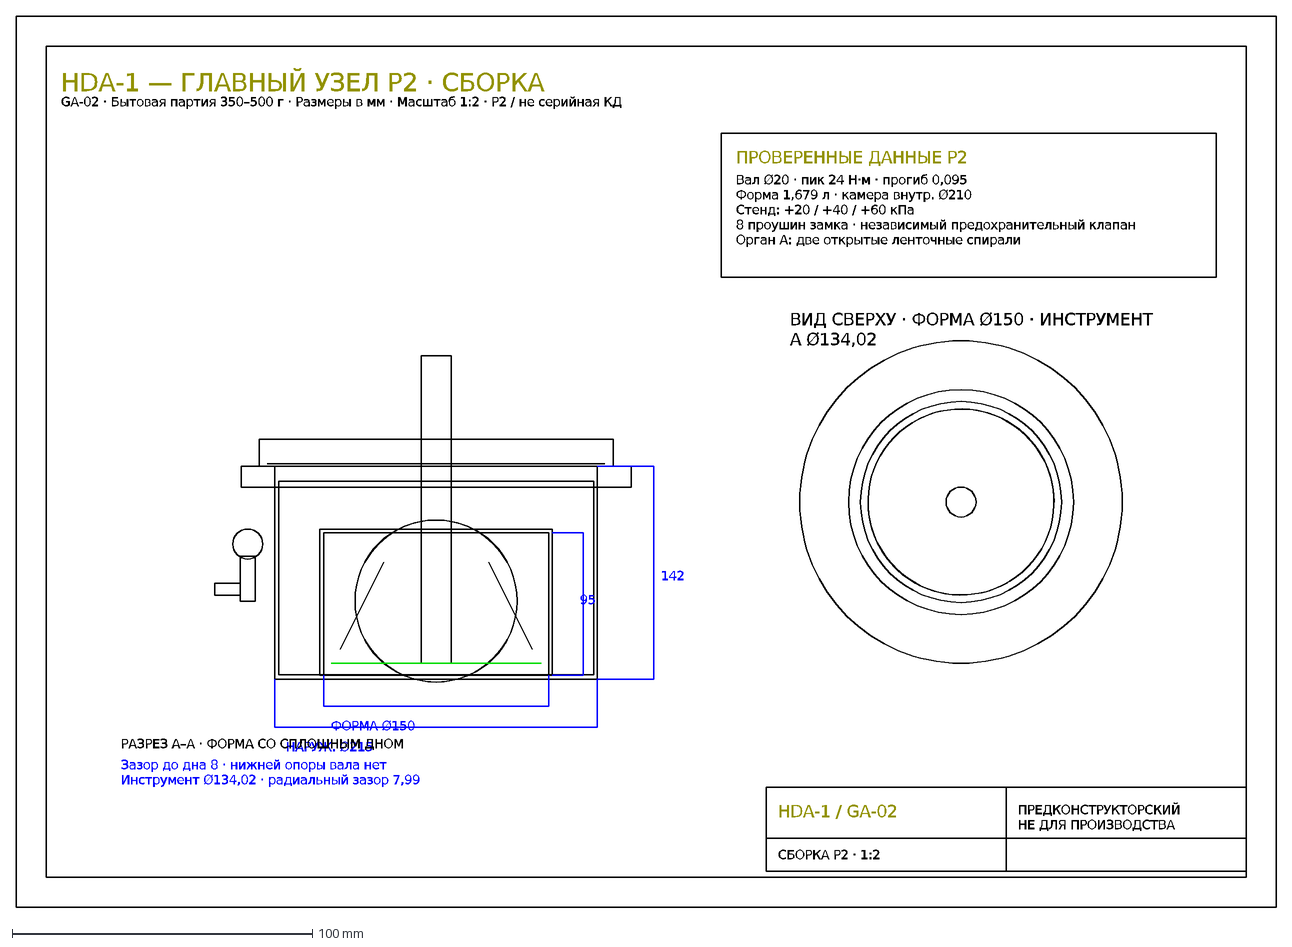
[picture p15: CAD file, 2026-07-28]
assets/p2/hda1_p2_ga02_ru.dxf
HDA-1 — ГЛАВНЫЙ УЗЕЛ P2 · СБОРКА
GA-02 · Бытовая партия 350–500 г · Размеры в мм · Масштаб 1:2 · P2 / не серийная КД
НАРУЖ. Ø215
ФОРМА Ø150
142
95
РАЗРЕЗ А–А · ФОРМА СО СПЛОШНЫМ ДНОМ
Зазор до дна 8 · нижней опоры вала нет
Инструмент Ø134,02 · радиальный зазор 7,99
ВИД СВЕРХУ · ФОРМА Ø150 · ИНСТРУМЕНТ A Ø134,02
ПРОВЕРЕННЫЕ ДАННЫЕ P2
Вал Ø20 · пик 24 Н·м · прогиб 0,095 Форма 1,679 л · камера внутр. Ø210 Стенд: +20 / +40 / +60 кПа 8 проушин замка · независимый предохранительный клапан Орган A
HDA-1 / GA-02
СБОРКА P2 · 1:2
ПРЕДКОНСТРУКТОРСКИЙ НЕ ДЛЯ ПРОИЗВОДСТВА

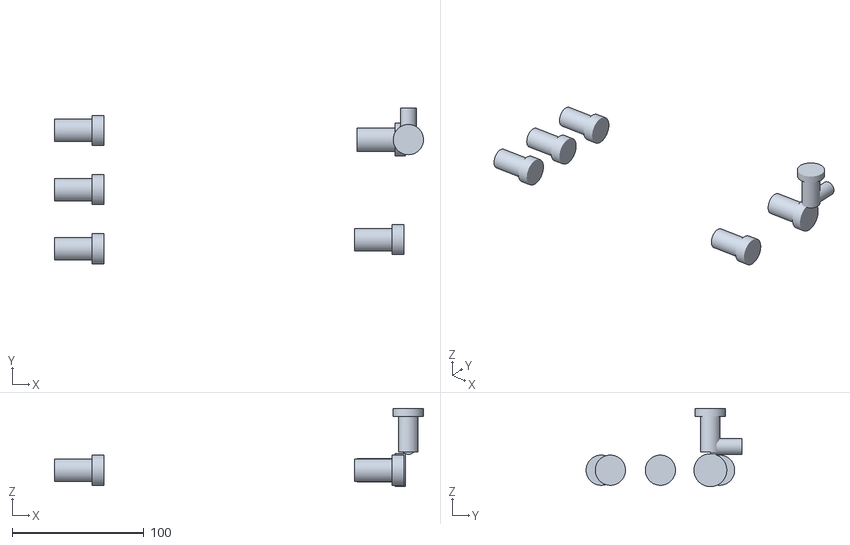
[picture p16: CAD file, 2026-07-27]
models/hda1_ports.stl
280.5 x 118.5 x 59.5

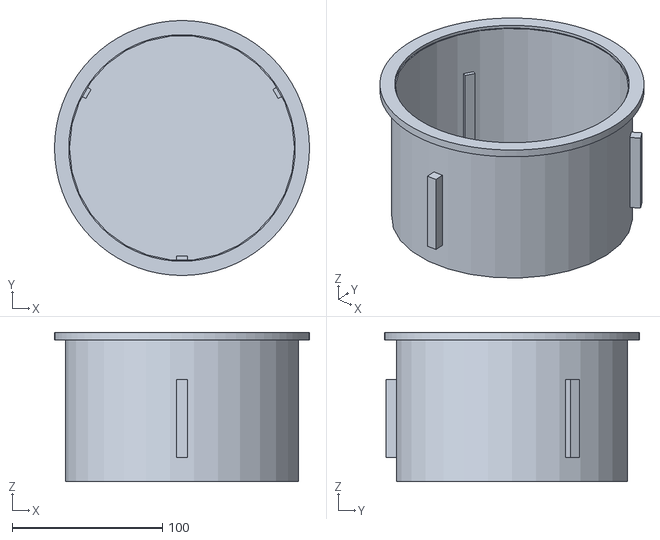
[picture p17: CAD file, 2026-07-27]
models/hda1_pan.stl
170.0 x 170.0 x 99.5

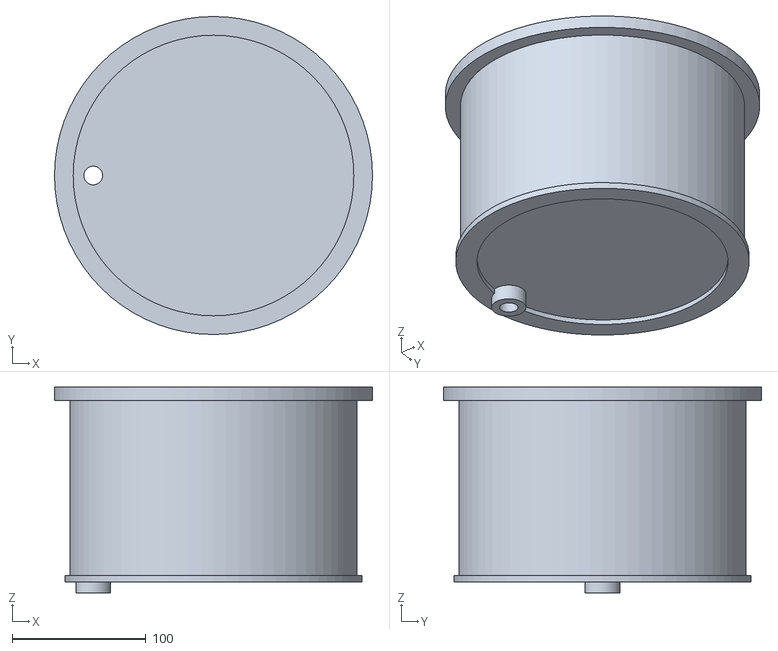
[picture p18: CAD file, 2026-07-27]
models/hda1_chamber.stl
238.0 x 238.0 x 154.0

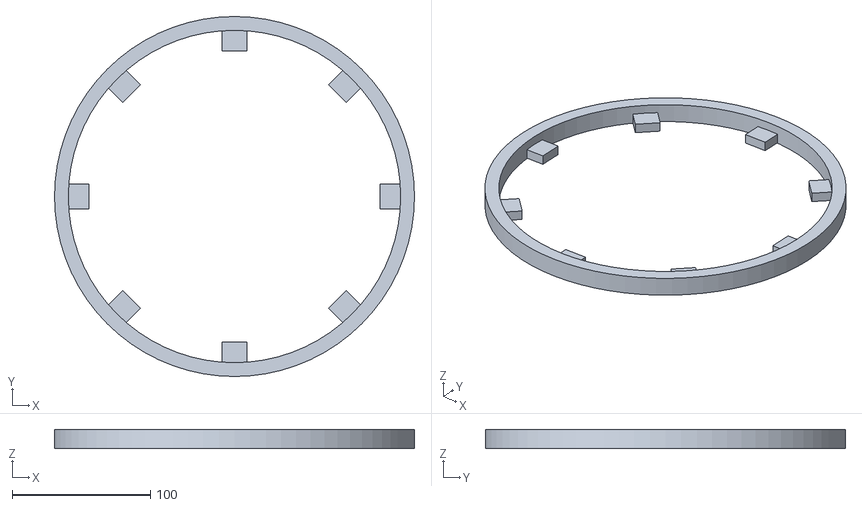
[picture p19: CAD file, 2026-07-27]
models/hda1_lock_ring.stl
260.0 x 260.0 x 14.0

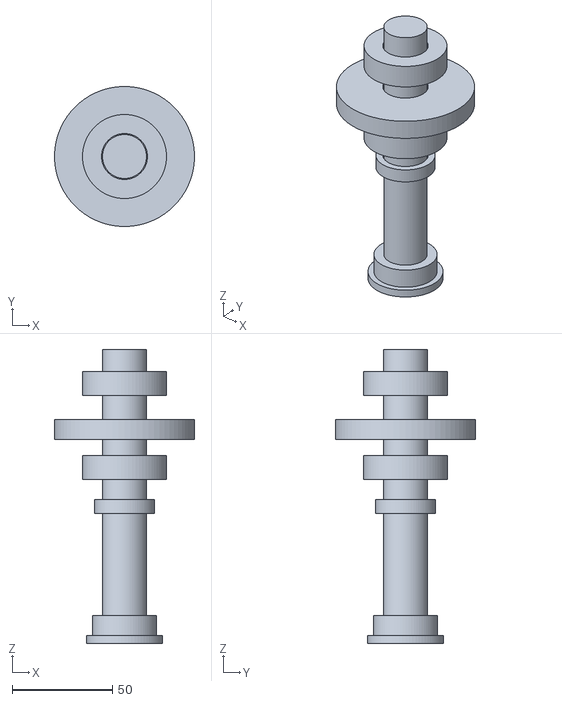
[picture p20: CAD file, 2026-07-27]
models/hda1_spindle.stl
70.0 x 70.0 x 147.0

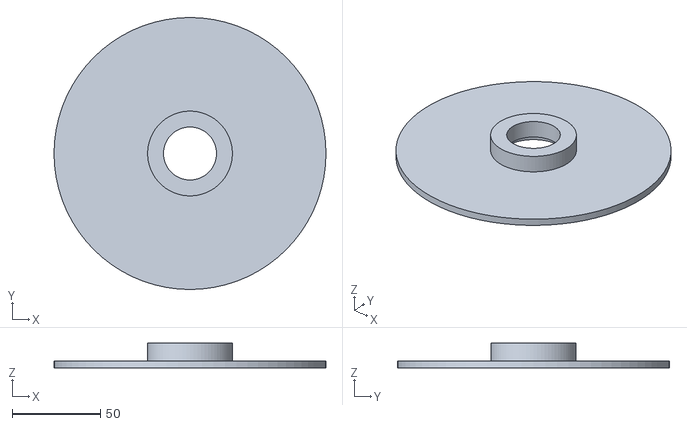
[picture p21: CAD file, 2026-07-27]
models/hda1_splash.stl
154.0 x 154.0 x 14.0

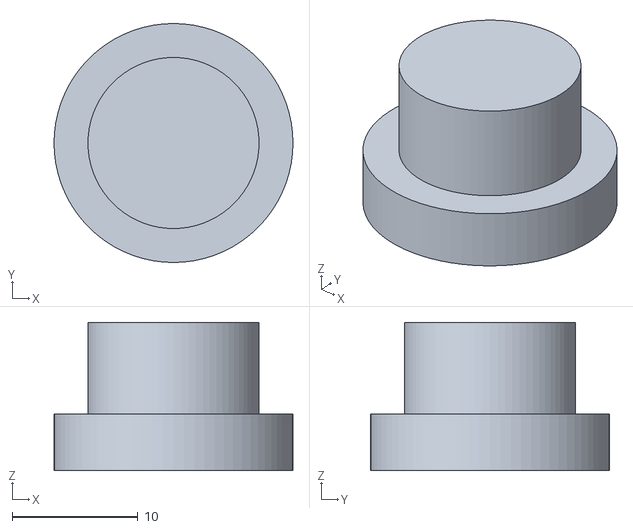
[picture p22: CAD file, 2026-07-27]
models/hda1_drain_cap.stl
19.0 x 19.0 x 11.8

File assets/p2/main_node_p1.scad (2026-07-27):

/*
 HDA-1 P1 — pre-design main-node geometry (millimetres).
 P1 has a 2.5 mm nominal shell, 3 mm lower closure, 10 mm lid plate and
 8-lug ring selected by preliminary screening. It is NOT production CAD,
 not an EN 13445 calculation and not pressure-equipment approval.
 PART = assembly|chamber|drain_cap|pan|lid|gasket|lock_ring|seal|splash|spindle|mixer|ports|motor
*/

PART = "assembly";
CUTAWAY = true;
$fn = 72;

// ---- P1 design envelope and preliminary pressure boundary ----
pressure_working_mpa = 0.15;
pressure_design_mpa = 0.25;
pressure_hydrotest_mpa = 0.325;
design_temp_c = 60;
chamber_id = 210;
shell_t = 2.5;                 // P1 nominal, requires final code calculation
bottom_t = 3.0;                // P1 nominal closure, requires final code calculation
chamber_od = chamber_id + 2*shell_t;
chamber_h = 142;
top_flange_od = 238;
top_flange_h = 10;
lid_od = 236;
lid_h = 18;
lid_plate_t = 10;
ring_od = 260;
ring_id = 240;
ring_h = 14;
lug_count = 8;
lug_t = 7;
lug_engagement = 18;
pan_top_od = 160;
pan_bottom_od = 146;
pan_inner_h = 92;
pan_rim_od = 170;
pan_t = 2.2;
shaft_d = 22;
splash_od = 154;
mixer_span = 130;
mixer_floor_clear = 7;
motor_offset = 95;
gasket_major_d = 220;
gasket_minor_d = 5;
drain_offset = -90;
pan_z = 13;
mixer_z = pan_z + pan_t + mixer_floor_clear;

gap_pan_chamber = (chamber_id-pan_top_od)/2;
gap_mixer_pan = (pan_top_od-mixer_span)/2;
assert(shell_t >= 2.5, "P1 shell nominal must not be reduced without recalculation");
assert(bottom_t >= 3, "P1 bottom nominal must not be reduced without recalculation");
assert(lid_plate_t >= 10, "P1 lid plate must not be reduced without recalculation");
assert(lug_count == 8 && lug_t >= 7 && lug_engagement >= 18,
       "P1 lock screen assumes 8 lugs, 7 mm thickness and 18 mm engagement");
assert(gap_pan_chamber > 10, "pan-to-chamber radial clearance");
assert(gap_mixer_pan >= 12, "mixer-to-pan radial clearance");
assert(mixer_floor_clear >= 7, "mixer floor clearance");
assert(abs(drain_offset)-13 > pan_bottom_od/2, "drain must remain outside pan footprint");
assert(abs(drain_offset)+13 < chamber_id/2, "drain must remain inside chamber footprint");

// ---- helpers ----
module annulus(od,id,h) { difference(){ cylinder(d=od,h=h); translate([0,0,-.1]) cylinder(d=id,h=h+.2); } }
module x_cyl(d,l) { rotate([0,90,0]) cylinder(d=d,h=l,center=true); }
module y_cyl(d,l) { rotate([90,0,0]) cylinder(d=d,h=l,center=true); }
module torus_like(major_d,minor_d) { rotate_extrude() translate([major_d/2,0,0]) circle(d=minor_d); }
function polar_xyz(r,a,z) = [r*cos(a),r*sin(a),z];
module rod_path(points,d=3) {
  for(i=[0:len(points)-2]) hull() { translate(points[i]) sphere(d=d,$fn=24); translate(points[i+1]) sphere(d=d,$fn=24); }
}
module sectioned() { if(CUTAWAY) difference(){ children(); translate([0,0,-40]) cube([340,340,410]); } else children(); }

// ---- stationary pressure boundary ----
module chamber() {
  color([0.30,0.34,0.38])
  difference() {
    union() {
      cylinder(d=chamber_od,h=chamber_h);
      // P1 lower external foot ring: not a thick pressure bottom.
      translate([0,0,-4]) annulus(222,190,5);
      // Separate forged/welded upper flange envelope.
      translate([0,0,chamber_h-top_flange_h]) cylinder(d=top_flange_od,h=top_flange_h);
      // Offset drain boss in the annular space; never below the mixer axis.
      translate([drain_offset,0,-12]) cylinder(d=26,h=15);
    }
    translate([0,0,bottom_t]) cylinder(d=chamber_id,h=chamber_h+.2);
    translate([drain_offset,0,-13]) cylinder(d=14,h=27);
  }
}

module drain_cap() {
  color([0.72,0.48,0.10]) {
    translate([drain_offset,0,-17]) cylinder(d=19,h=4.5);
    translate([drain_offset,0,-12.7]) cylinder(d=13.6,h=7.5);
  }
}

// ---- product pan: removable and not a pressure boundary ----
module pan() {
  color([0.14,0.72,0.70]) union() {
    difference() {
      cylinder(d1=pan_bottom_od,d2=pan_top_od,h=pan_inner_h+pan_t);
      translate([0,0,pan_t]) cylinder(d1=pan_bottom_od-2*pan_t,d2=pan_top_od-2*pan_t,h=pan_inner_h+.2);
    }
    translate([0,0,pan_inner_h+pan_t-3]) annulus(pan_rim_od,pan_top_od-5,5);
    for(a=[30,150,270]) rotate([0,0,a]) translate([79,0,42]) cube([15,8,52],center=true);
  }
}

// ---- lid and 8-lug self-locking ring ----
module lid() {
  color([0.50,0.54,0.58]) union() {
    difference() {
      cylinder(d=lid_od,h=lid_h);
      // Underside pocket leaves a 10 mm central P1 plate; final FEA required.
      translate([0,0,-.1]) cylinder(d=180,h=lid_h-lid_plate_t+.1);
      // Static-gasket service groove, separated from the pressure opening.
      translate([0,0,-.1]) annulus(228,212,4.7);
    }
    translate([0,0,lid_h-3]) cylinder(d=108,h=3);
  }
}

module gasket() {
  color([0.92,0.33,0.08]) translate([0,0,2]) torus_like(gasket_major_d,gasket_minor_d);
}

module lock_ring() {
  color([0.94,0.55,0.12]) union() {
    annulus(ring_od,ring_id,ring_h);
    // Eight inward lugs: nominal 7 mm thick, 18 mm radial engagement.
    for(a=[0:360/lug_count:359]) rotate([0,0,a]) translate([114,0,4]) cube([lug_engagement,18,lug_t],center=true);
    // Outer grip ribs; they are not pressure load paths.
    for(a=[15:30:345]) rotate([0,0,a]) translate([ring_od/2-4,0,ring_h/2]) cube([6,10,ring_h-3],center=true);
  }
}

// ---- upper-supported spindle; no bottom support in the bowl ----
module spindle() {
  color([0.55,0.58,0.60]) translate([0,0,106]) cylinder(d=shaft_d,h=142);
  color([0.12,0.12,0.13]) translate([0,0,183]) annulus(42,shaft_d+1,12);
  color([0.12,0.12,0.13]) translate([0,0,225]) annulus(42,shaft_d+1,12);
  color([0.14,0.18,0.22]) translate([0,0,203]) annulus(70,shaft_d+1,10);
  color([0.86,0.68,0.15]) translate([0,0,166]) annulus(30,shaft_d+1,7);
  color([0.24,0.30,0.34]) translate([0,0,103]) cylinder(d=32,h=12);
  color([0.90,0.62,0.10]) translate([0,0,101]) cylinder(d=38,h=4);
}

module seal() {
  color([0.14,0.15,0.16]) translate([0,0,145]) annulus(56,shaft_d+2,16);
  color([0.82,0.30,0.08]) translate([0,0,150]) annulus(70,56,7);
  color([0.05,0.10,0.14]) difference() { translate([0,0,161]) annulus(78,60,14); translate([28,-12,160]) cube([30,24,17]); }
  color([0.25,0.75,0.85]) translate([36,0,162]) rotate([0,90,0]) cylinder(d=12,h=20);
}

module splash() {
  color([0.18,0.55,0.72]) difference() {
    translate([0,0,112]) annulus(splash_od,38,4);
    for(a=[0:90:270]) rotate([0,0,a]) translate([54,0,111]) cube([24,16,7],center=true);
  }
  color([0.18,0.55,0.72]) translate([0,0,116]) annulus(48,30,10);
}

// ---- P0 calculated hybrid mixer retained for P1 prototype comparison ----
module lower_swept_paddle(a=0) {
  rotate([0,0,a]) union() {
    hull() { translate([13,0,1]) cylinder(d=3,h=28,$fn=24); translate([38,6,3]) cylinder(d=3,h=28,$fn=24); }
    hull() { translate([38,6,3]) cylinder(d=3,h=28,$fn=24); translate([64,14,6]) cylinder(d=3,h=25,$fn=24); }
    hull() { translate([11,-4,2]) cylinder(d=6,h=26,$fn=24); translate([22,1,2]) cylinder(d=6,h=27,$fn=24); }
  }
}
module aerator_wire(a=0) {
  rotate([0,0,a]) rod_path([
    polar_xyz(13,0,39), polar_xyz(28,4,45), polar_xyz(40,8,51), polar_xyz(47,11,58),
    polar_xyz(49,12,64), polar_xyz(47,11,70), polar_xyz(40,8,78), polar_xyz(28,4,84), polar_xyz(13,0,88)
  ],3);
}
module mixer() {
  color([0.10,0.84,0.78]) union() {
    cylinder(d=shaft_d,h=96);
    cylinder(d=30,h=32);
    lower_swept_paddle(0); lower_swept_paddle(180);
    translate([0,0,34]) cylinder(d=30,h=8);
    for(a=[0:45:315]) aerator_wire(a);
    translate([0,0,84]) cylinder(d=30,h=8);
    translate([0,0,92]) cylinder(d1=30,d2=32,h=12);
  }
}

// ---- separate pressure ports and a recognisable safety valve envelope ----
module port_body(x,y,z,col=[0.8,0.2,0.1]) {
  color(col) translate([x,y,z]) x_cyl(17,30);
  color([0.18,0.18,0.18]) translate([x+18,y,z]) x_cyl(23,9);
}
module relief_valve_p1() {
  // Envelope of a purchased, independently certified spring safety valve.
  color([0.88,0.16,0.10]) translate([116,38,112]) x_cyl(18,30);
  color([0.18,0.18,0.18]) translate([134,38,112]) x_cyl(25,8);
  color([0.88,0.16,0.10]) translate([140,38,126]) cylinder(d=15,h=27);
  color([0.20,0.20,0.21]) translate([140,38,153]) cylinder(d=23,h=6);
  color([0.88,0.16,0.10]) translate([140,50,130]) y_cyl(12,24);
}
module ports() {
  port_body(-114,-45,112,[0.18,0.65,0.90]); // P1
  port_body(-114,0,112,[0.55,0.24,0.82]);   // P2
  port_body(-114,45,112,[0.20,0.72,0.42]);  // inlet
  port_body(114,-38,112,[0.95,0.58,0.10]);  // controlled exhaust
  relief_valve_p1();                         // independent mechanical relief
}
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

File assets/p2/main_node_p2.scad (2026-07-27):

/*
 HDA-1 P2 — assembly wrapper around the reviewed P1 pressure-boundary envelope.
 P2 replaces only the unproven P1 mixer with the P2-B test candidate.
 Units: millimetres.  Not production CAD or a pressure-equipment calculation.
 PART = assembly|chamber|drain_cap|pan|lid|gasket|lock_ring|seal|splash|spindle|mixer|ports|motor
*/

use <main_node_p1.scad>;
use <p2_mixer_variants.scad>;

PART = "assembly";
CUTAWAY = true;

// P2 form: constant Ø150 mm inner bore; 1.68 L nominal geometric volume.
// Its 2.5 mm bottom top is z=15.5 mm. The tool itself begins 8 mm above it.
p2_pan_inner_d = 150;
p2_pan_inner_h = 95;
p2_pan_t = 2.5;
p2_pan_outer_d = 155;
p2_pan_rim_d = 170;
p2_pan_z = 13;
p2_tool_origin_z = p2_pan_z + p2_pan_t;

module pan_p2() {
  color([0.14,0.72,0.70]) union() {
    difference() {
      cylinder(d=p2_pan_outer_d,h=p2_pan_inner_h+p2_pan_t);
      translate([0,0,p2_pan_t]) cylinder(d=p2_pan_inner_d,h=p2_pan_inner_h+.2);
    }
    translate([0,0,p2_pan_inner_h+p2_pan_t-3]) annulus(p2_pan_rim_d,p2_pan_outer_d-4,5);
    // Three external keys prevent the removable form from rotating, outside the food volume.
    for(a=[30,150,270]) rotate([0,0,a]) translate([78,0,42]) cube([12,7,52],center=true);
  }
}

module p2_mixer() {
  // P2-A is the baseline: two connected open helical ribbons.
  // P2-B with the slotted ring remains a separate experimental alternative.
  // It has no lower support. Its lowest steel point remains z=23.2 mm.
  translate([0,0,p2_tool_origin_z]) tool_A();
}

module main_assembly_p2() {
  sectioned() chamber();
  sectioned() drain_cap();
  sectioned() translate([0,0,p2_pan_z]) pan_p2();
  sectioned() translate([0,0,142]) lid();
  sectioned() translate([0,0,142]) gasket();
  sectioned() translate([0,0,128]) lock_ring();
  sectioned() spindle();
  sectioned() seal();
  sectioned() splash();
  sectioned() ports();
  sectioned() motor();
  sectioned() p2_mixer();
}

if(PART=="assembly") main_assembly_p2();
else if(PART=="chamber") chamber();
else if(PART=="drain_cap") drain_cap();
else if(PART=="pan") translate([0,0,p2_pan_z]) pan_p2();
else if(PART=="lid") translate([0,0,142]) lid();
else if(PART=="gasket") translate([0,0,142]) gasket();
else if(PART=="lock_ring") translate([0,0,128]) lock_ring();
else if(PART=="seal") seal();
else if(PART=="splash") splash();
else if(PART=="spindle") spindle();
else if(PART=="mixer") p2_mixer();
else if(PART=="ports") ports();
else if(PART=="motor") motor();
else assert(false,str("Unknown PART: ",PART));

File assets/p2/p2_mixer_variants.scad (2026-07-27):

/*
 HDA-1 P2 — two testable, top-driven mixer candidates.
 Units: millimetres.  These are prototype tools, not serial production parts.
 Both are completely above the pan floor: there is no lower bearing/support.
 PART = "A" | "B" | "compare"
*/

PART = "compare";
$fn = 96;

// P2 insert: ID 150 mm, 95 mm working height. Tool geometry.
shaft_d = 20;
hub_d = 34;
tool_od = 134;                 // 8 mm radial clearance to nominal 150 mm form
tool_radius = 62;
floor_clear = 8;
ribbon_h = 76;
ribbon_radial_w = 10;
ribbon_t = 2.5;

assert(tool_od <= 150 - 2*floor_clear, "tool must retain radial food clearance");
assert(floor_clear >= 7, "no lower support: floor clearance must be >= 7 mm");

module ribbon(phase=0) {
  // A solid rectangular helical band: open, washable, no tube or wire loop.
  rotate([0,0,phase])
    linear_extrude(height=ribbon_h, twist=300, slices=48)
      translate([tool_radius-ribbon_radial_w/2, -ribbon_t/2])
        square([ribbon_radial_w,ribbon_t], center=false);
}

module quick_coupling() {
  // Four torque dogs; their strength is calculated separately from the visual model.
  cylinder(d=hub_d,h=18);
  for(a=[0:90:270]) rotate([0,0,a]) translate([15,0,9]) cube([10,7,7],center=true);
}

module tool_A() {
  color([0.72,0.76,0.78]) union() {
    // The central shaft begins 8 mm above the form floor: it is not a lower support.
    translate([0,0,floor_clear]) cylinder(d=20,h=ribbon_h+26);
    translate([0,0,floor_clear+ribbon_h+8]) quick_coupling();
    translate([0,0,floor_clear]) ribbon(0);
    translate([0,0,floor_clear]) ribbon(180);
    // Two lower and two upper radial ties make the helices one load path to the hub.
    for(a=[0,180]) rotate([0,0,a]) {
      translate([36,0,floor_clear+2.5]) cube([56,7,5],center=true);
      translate([36,0,floor_clear+ribbon_h-2.5]) cube([56,7,5],center=true);
    }
  }
}

module disperser_ring() {
  // A shallow, balanced annular disc with large open slots — not a random fan.
  difference() {
    cylinder(d=112,h=4);
    translate([0,0,-.1]) cylinder(d=42,h=4.2);
    // Slots stop short of both inner and outer rings; the disc remains one part.
    for(a=[0:45:315]) rotate([0,0,a]) translate([40,0,2]) cube([26,13,4.2],center=true);
  }
}

module tool_B() {
  color([0.72,0.76,0.78]) union() {
    translate([0,0,floor_clear]) cylinder(d=20,h=ribbon_h+26);
    translate([0,0,floor_clear+ribbon_h+8]) quick_coupling();
    translate([0,0,floor_clear]) ribbon(0);
    translate([0,0,floor_clear]) ribbon(180);
    for(a=[0,180]) rotate([0,0,a]) {
      translate([36,0,floor_clear+2.5]) cube([56,7,5],center=true);
      translate([36,0,floor_clear+ribbon_h-2.5]) cube([56,7,5],center=true);
    }
    // Four short bridges tie the upper disperser annulus to the central shaft.
    for(a=[0:90:270]) rotate([0,0,a]) translate([16,0,68]) cube([22,6,4],center=true);
    translate([0,0,66]) disperser_ring();
  }
}

module pan_reference() {
  color([0.15,0.65,0.70,0.18]) difference() {
    cylinder(d=150,h=95);
    translate([0,0,2]) cylinder(d=146,h=94);
  }
}

if(PART == "A") tool_A();
else if(PART == "B") tool_B();
else if(PART == "compare") {
  translate([-92,0,0]) { pan_reference(); tool_A(); }
  translate([92,0,0]) { pan_reference(); tool_B(); }
}
else assert(false, str("Unknown PART: ", PART));

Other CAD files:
models/hda1_seal.stl
models/hda1_gasket.stl
assets/p2/HDA1_P2_Master.FCStd

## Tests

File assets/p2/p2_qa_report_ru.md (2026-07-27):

# HDA-1 — цифровая QA-проверка P2

Дата: 28.07.2026. Проверка относится к цифровой модели и визуальным материалам P2; она не заменяет физические испытания.

## 1. Экспорт параметрической сборки

- Источник: `main_node_p2.scad`.
- Экспорт: `scripts/render_p2.ps1`.
- Выгружено 12 STL: камера, слив, P2-форма, крышка, уплотнение, кольцо, кассета уплотнения, экран, вал, мешалка, порты, двигатель.
- Экспорт завершён без диагностических ошибок OpenSCAD.

## 2. Проверка STL

`tools/validate_stl.py` подтвердил для P2:

- конечные координаты и ненулевые грани;
- замкнутые поверхности (каждое ребро принадлежит двум граням);
- корректную ориентацию общих рёбер;
- ненулевые объёмы компонентов;
- цельную связную мешалку P2-B: 3 012 треугольников, без предупреждений;
- цельную связную P2-форму: 908 треугольников, без предупреждений.

У нескольких сборочных STL (уплотнение, шпиндель, порты) несколько связных компонентов ожидаемы, потому что это экспорт визуально разделённых подсборок; каждый компонент замкнут.

## 3. Контроль геометрических инвариантов

`calculations/p2_geometry_checks.js` — PASS:

| Проверка | Результат |
|---|---:|
| Объём формы в диапазоне 1,2–1,8 л | 1,679 л |
| Радиальный зазор мешалка–форма ≥7 мм | 7,989 мм |
| Зазор до дна ≥7 мм | 8,0 мм |
| Нижняя опора отсутствует | PASS |
| Верх мешалки остаётся ниже нижней плоскости крышки | 16,5 мм запаса |
| Диаметр мокрого вала | Ø20 мм |

Именно этот контроль обнаружил несоответствие с ранней конической P1-формой. P2-форма была изменена на постоянный Ø150 мм до финального экспорта.

## 4. Визуальная QA

- P2-сборка отрендерена в Blender Cycles GPU (AMD Radeon 780M), 1200 × 900, 32 samples, adaptive + OIDN.
- Проверены: отсутствие нижней опоры, читаемость съёмной формы и верхнего вала, отдельный красный предохранительный клапан, наличие кольцевого замка, отсутствие «лент Мёбиуса» или разорванной геометрии.
- GA-02 сформирован как SVG, отрендерен в PNG и вручную просмотрен. На листе нет стрелочных выносок, указывающих не на детали; смысловые пояснения вынесены в текстовые блоки.

## 5. Намеренно не заявляется как завершённое

1. Эффективность вспенивания и качество выпечки — требуют 54 физических циклов.
2. FEM, усталость, сварка, герметизация и расчёт сосуда по нормам — требуют инженера по оборудованию под давлением.
3. Реальная настройка аварийного клапана, расход сброса и электробезопасность — требуют поставщиков и испытаний.

P2 цифрово согласован; его функциональная валидность пока не доказана и этим документом не подменяется.

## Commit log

2026-07-27 Publish interactive HDA-1 3D viewer
    [hda1_chamber.stl, hda1_drain_cap.stl, hda1_gasket.stl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]
2026-07-27 Update viewer to HDA-1 P1
    [hda1_chamber.stl, hda1_drain_cap.stl, hda1_lid.stl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]
2026-07-27 Publish HDA-1 P1 engineering package
    [main_node_p1.scad]
2026-07-27 Publish HDA-1 P2 model, drawings and engineering package
    [hda1_chamber.stl, hda1_drain_cap.stl, hda1_lid.stl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]
2026-07-27 Include P2 CAD source dependencies
    [main_node_p1.scad, p2_mixer_variants.scad]
2026-07-27 Add native DXF GA-02 CAD drawing
    [hda1_p2_ga02_ru.dxf]
2026-07-28 Publish mobile PDF and corrected GA-02 sheet
    [hda1_p2_ga02_ru.dxf]
2026-07-28 Publish LibreCAD-reviewed GA-03 drawing
    [hda1_p2_ga03_preliminary_ru.dxf]
2026-07-28 Add FreeCAD native model and detailed GA05 package
    [HDA1_P2_Master.FCStd, HDA1_P2_Master.step]
2026-07-28 Remove rejected GA05 and add checked drawing source
    [hda1_p2_ga06_detailed_projections_ru.dxf]
2026-07-28 Publish verified GA06 and 15-page P2 package
    [hda1_p2_ga06_detailed_projections_ru.dxf]
